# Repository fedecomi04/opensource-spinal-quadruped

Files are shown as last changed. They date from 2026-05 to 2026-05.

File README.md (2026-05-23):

# ASTRA — Quasi-Direct-Drive Spinal Quadruped

**Active Spine Technology for Robotic Agility** — an open-source 9.5 kg quadruped robot with a 3-DoF active spine, built as a B.Sc. thesis at TU München. Designed to be reproducible by hobbyists and labs for around **€1 500**, with full mechanical CAD, embedded firmware, and ROS 2 control stack.

<p align="center">
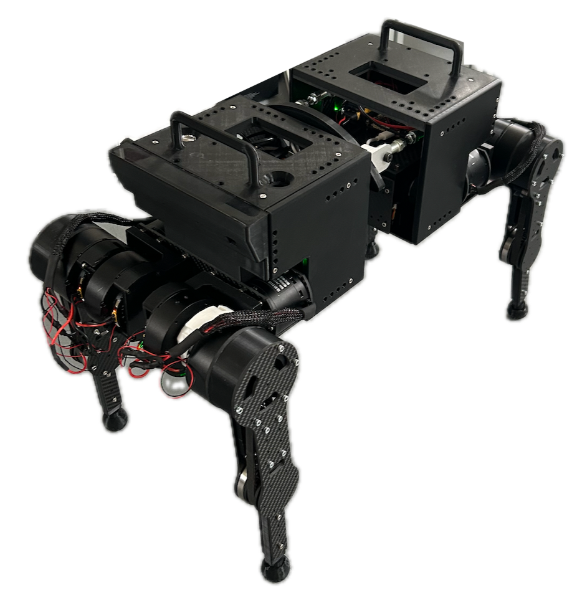
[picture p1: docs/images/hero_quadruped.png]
ASTRA quadruped
  
</p>

---

## Why this project

The 2020s have seen quadrupeds like Unitree's **Go2** (~€2 800) and Boston Dynamics' **Spot** (~€75 000) move from labs into the consumer/industrial market. But almost every commercial platform has a **rigid torso**. Biology disagrees: cheetahs, dogs and horses use their spine to extend stride, store elastic energy and rotate the body in flight.

ASTRA is a **research platform built specifically to study active spines**, with a parallel three-DoF spine that can be locked rigid (to baseline against rigid-torso behaviour) or driven actively. The full stack — CAD, firmware, ROS 2 nodes, MuJoCo sim — is released so anyone with a printer, a soldering iron and a ~€1.5k budget can rebuild it and run new control algorithms.

<p align="center">
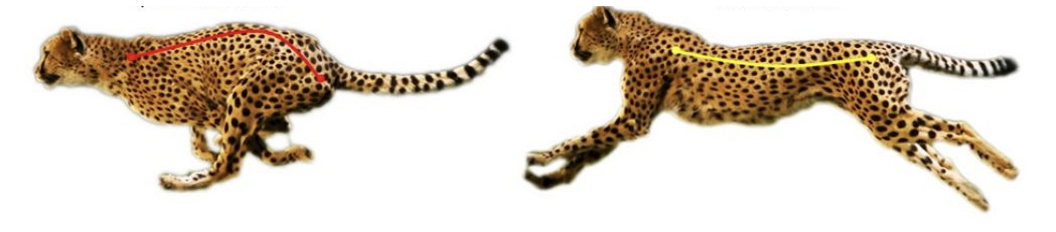
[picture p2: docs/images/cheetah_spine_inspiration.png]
Cheetah spine flexion
  
  <br/>
  <em>Biological inspiration: spine flexion/extension in a running cheetah.</em>
</p>

---

## Key specifications

| | ASTRA | MIT Mini Cheetah | ANYmal | Spot |
|---|---|---|---|---|
| **Mass** | **9.5 kg** | 9.0 kg | 50 kg | 32.7 kg |
| **Dimensions (l × w × h)** | **565 × 287 × 435 mm** | 480 × 270 × 300 | 930 × 530 × 890 | 1100 × 500 × 700 |
| **Max speed** | 4 cm/s¹ | 3.9 m/s | 1.3 m/s | 1.6 m/s |
| **Autonomy** | ~25 min | 30–120 min | 90 min | 90 min |
| **Active-spine DoF** | **3** | 0 | 0 | 0 |
| **Total DoF** | 15 (3 × 4 legs + 3 spine) | 12 | 12 | 12 |
| **Estimated build cost** | **~€1.5 k** | — | — | — |

¹ With the current hard-coded open-loop trot. The mechanical platform is designed for >1 m/s once a proper MPC / learned controller is added.

---

## Demos

### Balance on an inclined plane — real hardware

The spine actively rotates so that either the **front** or the **rear** body stays horizontal on a slope — selected by a single flag in the controller.

**Front body kept horizontal:**

<p align="center">
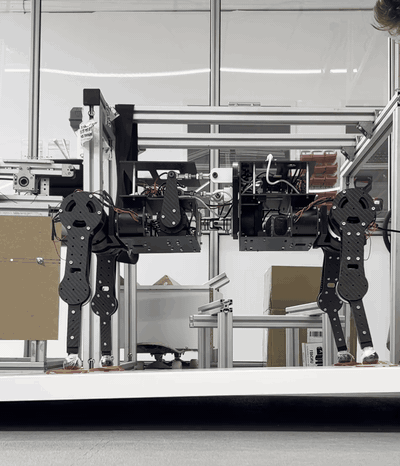
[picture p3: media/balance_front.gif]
  
</p>

**Rear body kept horizontal:**

<p align="center">
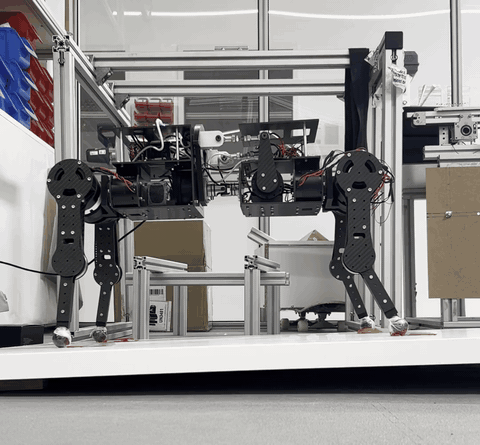
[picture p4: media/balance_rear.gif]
  
</p>

### Trot gait — MuJoCo simulation

The trot controller running in the MuJoCo physics simulation. Every algorithm is validated here before being deployed to the physical robot.

<p align="center">
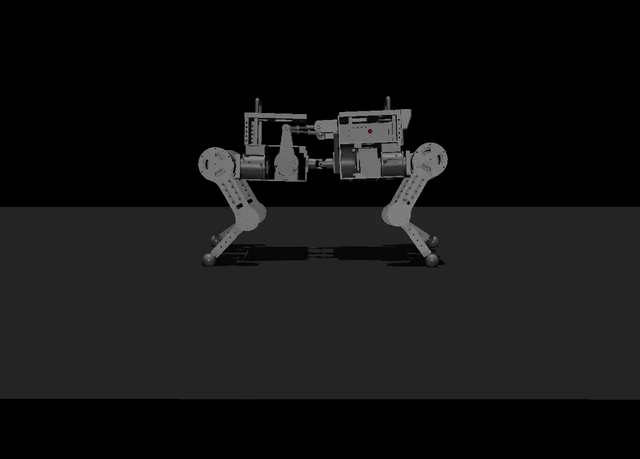
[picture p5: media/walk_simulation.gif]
  
</p>

> Full-resolution MP4 versions of all three clips are also in [`media/`](media/) (and as downloadable assets on the [`demos-v1` release](https://github.com/fedecomi04/opensource-spinal-quadruped/releases/tag/demos-v1)).

### Trot gait — real hardware (still)

<p align="center">
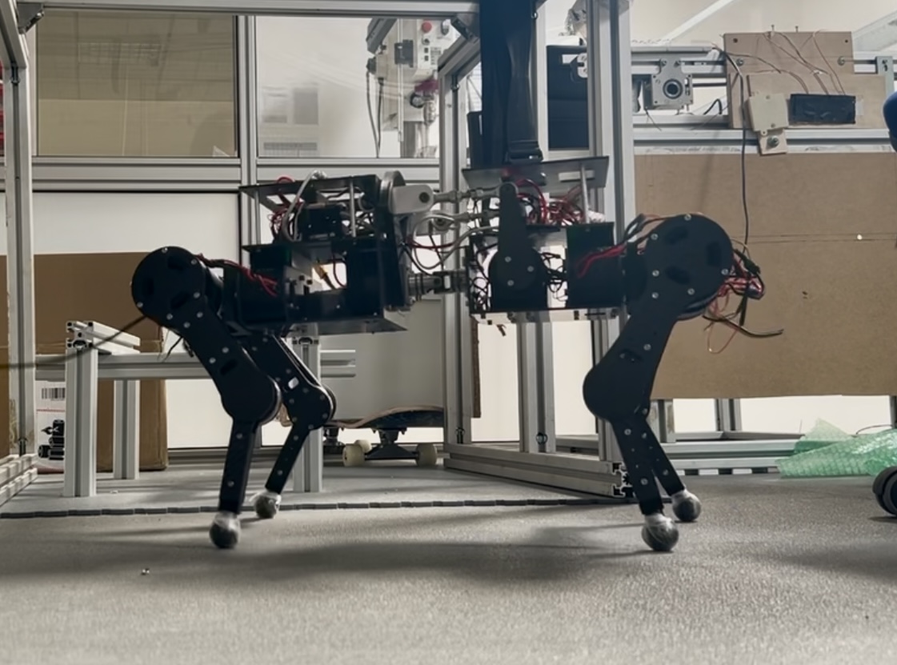
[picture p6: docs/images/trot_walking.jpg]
  
</p>

Hard-coded closed-loop quintic foot trajectory, diagonal pairs in phase, ~4 cm/s on the physical robot.

---

## Hardware

### Actuators — quasi-direct drive

| Joint | Motor | Qty | Reduction |
|---|---|---|---|
| Hip & waist (per leg) | Damiao **DM6006** | 8 | direct (1:1) |
| Knee (per leg) | Damiao **DM6006** | 1 + belt | **1.5:1 belt** → QDD |
| Spine (3 DoF) | Damiao **DM4010** | 6 | direct |

15 motors total. All Damiao motors integrate the BLDC driver on-board and expose a **CAN-FD** interface accepting MIT-mode torque control (θ, ω, K<sub>p</sub>, K<sub>d</sub>, τ<sub>ff</sub>). No external ESCs.

### Electronics architecture

<p align="center">
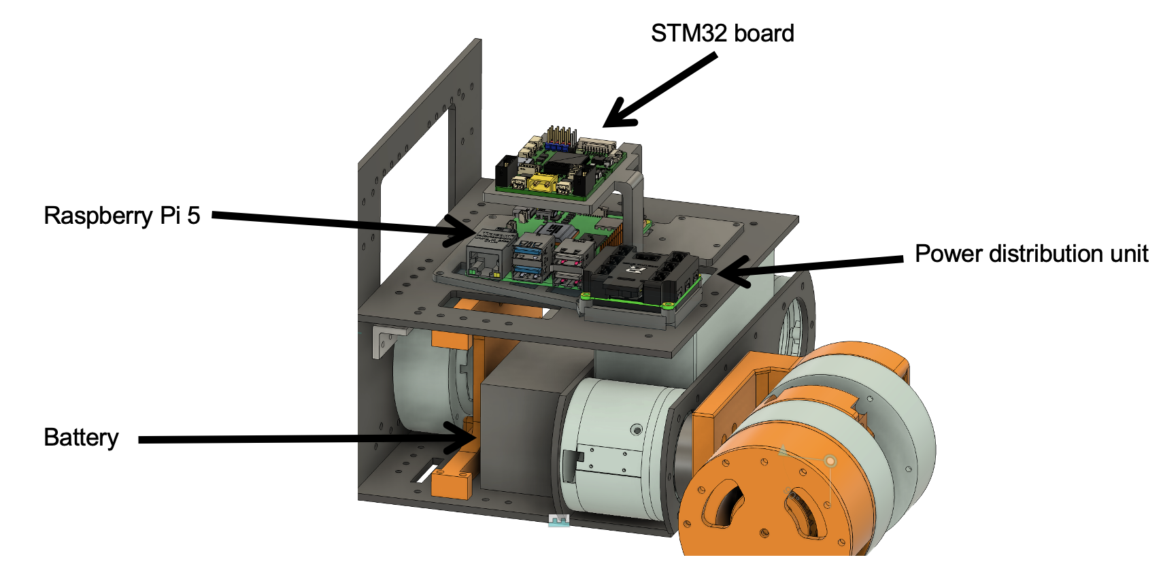
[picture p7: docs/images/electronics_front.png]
Front electronics
  
</p>

```
                        ┌─────────────────────────────┐
                        │     Raspberry Pi 5 (brain)  │
                        │     ROS 2 Jazzy, Ubuntu     │
                        └──────┬───────────────┬──────┘
                          USB  │               │  USB
                  ┌────────────▼───┐     ┌─────▼──────────┐
                  │  Front STM32H7 │     │  Rear STM32H7  │
                  │  (CAN bridge)  │     │  (CAN bridge)  │
                  └───┬────────┬───┘     └──┬───┬────┬────┘
                FDCAN1│  FDCAN2│        FDCAN1│ 2 │  3
                  ┌───▼─┐   ┌──▼─┐         ┌──▼┐ │  │
                  │FR M │   │FL M│         │RR M│ │  └─ spine
                  └─────┘   └────┘         └────┘ └─ RL M
```

- **Pi 5** acts as the brain — runs all ROS 2 nodes (non-real-time).
- **2 × STM32H723VG** boards handle the real-time CAN-FD bus (one per body half). Pi → STM32 over USB, STM32 → motors over CAN-FD at 1 Mbit/s arbitration + 5 Mbit/s data.
- **RoboMaster PDU** distributes 24 V from a 6S LiPo battery to the motors; the Pi runs off a separate power bank so a kill-switch can cut motor power without shutting down the controller.

This split lets you swap the Pi for any other host with a USB port — the motor stack stays intact.

### Mechanical design

<p align="center">
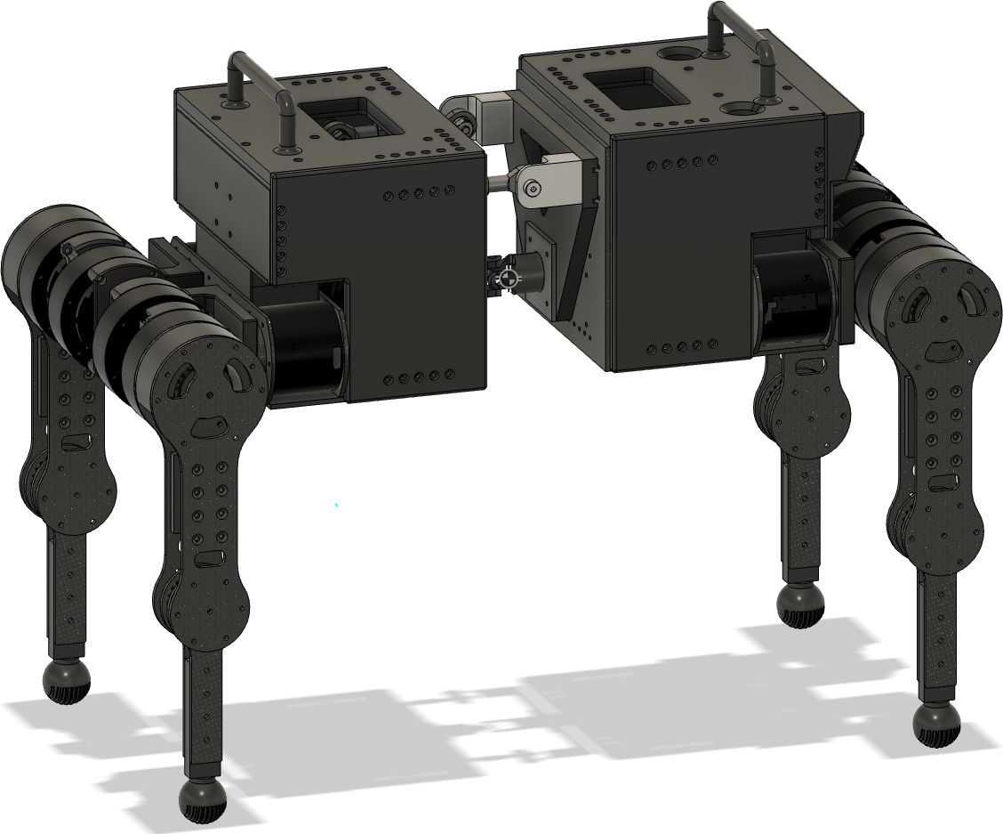
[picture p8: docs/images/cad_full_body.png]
  
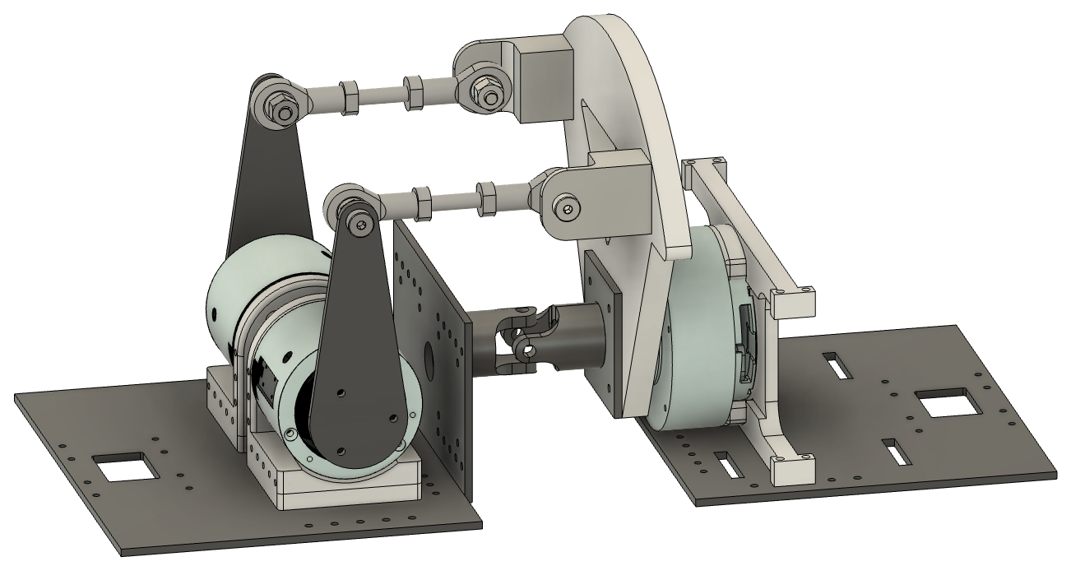
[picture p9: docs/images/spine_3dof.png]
  
  <br/>
  <em>Left: full body. Right: parallel 3-DoF spine mechanism (pitch, roll, yaw via 2 actuators + universal joint).</em>
</p>

- **CFRP** (carbon-fibre) frame and leg links — light, stiff, cheap to laser-cut.
- **Tough PLA** for the brackets and covers — printable on any consumer FDM printer.
- **Steel** link rods + universal joint for the spine.
- **1.5:1 toothed belt** at the knee for the QDD reduction.

### Mass breakdown

<p align="center">
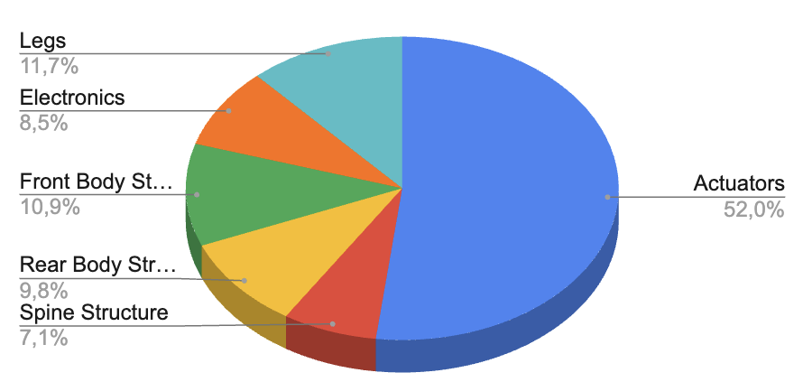
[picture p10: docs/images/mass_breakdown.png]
Mass distribution
  
</p>

| Subsystem | Mass [kg] | % of total |
|---|---:|---:|
| Actuators (15 motors) | 4.95 | 52 % |
| Front body structure | 1.04 | 11 % |
| Rear body structure | 0.94 | 10 % |
| Electronics (Pi, STM32, PDU, battery, wiring) | 0.86 | 9 % |
| Spine assembly | 0.67 | 7 % |
| Legs (4 ×) | 1.12 | 12 % |
| **Total** | **9.5** | **100 %** |

---

## Software

### ROS 2 nodes (`ros2_ws/src/`)

| Node | Role |
|---|---|
| `leg_command/` | Low-level motor command publisher. Accepts `"leg,joint,command"` strings and produces the 14-byte USB → CAN-FD frames for any single Damiao motor. Lets you fire one motor at a time from `ros2 topic pub` — invaluable for hardware bring-up. |
| `mujoco_interface/` | Bridges ROS 2 ↔ MuJoCo. Subscribes to `actuator_goal_rad` (15-vector of joint targets) and drives the simulated robot. Publishes a simulated `imu_data` topic. Supports both position and torque (PD) control modes. |
| `hardware_check/` | Boot-time calibration helper. On startup zeroes every motor in MIT mode, then walks through the 5 legs (FR, FL, RR, RL, S) at 5-second intervals so you can hand-position each one at its mechanical zero. |
| `trot/` | Hard-coded trot gait. Computes per-leg foot trajectories from a quintic smoothing function with configurable stride period, duty factor, swing height and phase offsets. Runs IK on each foot target to produce joint goals at 100 Hz, then publishes MIT commands at 33 Hz with a smooth gain ramp. |
| `spine_roll_inclined_plane/` | Inclined-plane balance controller. Reads IMU pitch, then drives the spine and rear legs so that either the **front** or **rear** body stays horizontal — selected by a single flag. |

<p align="center">
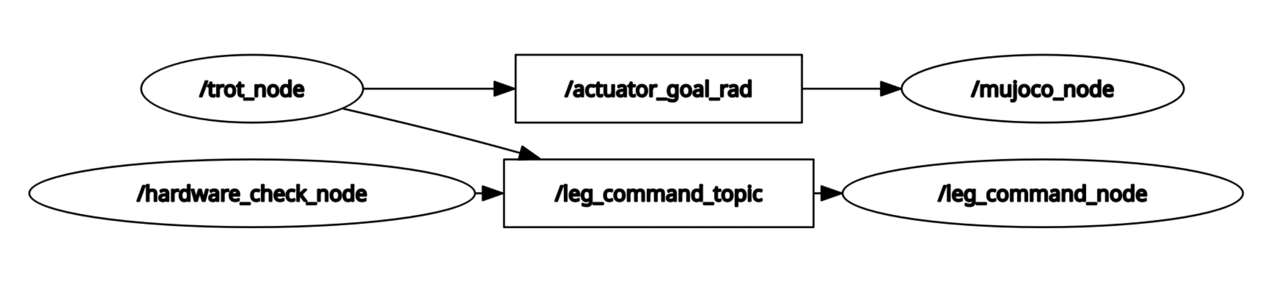
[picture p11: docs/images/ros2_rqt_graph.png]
ROS 2 rqt graph
  
  <br/>
  <em>Live rqt_graph of the running system.</em>
</p>

### STM32 firmware (`firmware/`)

Two STM32CubeIDE projects (`front_stm32/`, `rear_stm32/`) for the **STM32H723VG**:
- 2–3 FDCAN peripherals per board, each connected to one motor bus.
- USB CDC for Pi communication. Every 14-byte USB packet is unpacked into a CAN frame and forwarded.
- Receive interrupt callback re-packages CAN replies (e.g. motor position/velocity feedback) into USB packets for the Pi.

### Simulation (MuJoCo)

The **full MuJoCo simulation is shipped in the repo** at [`ros2_ws/src/mujoco_interface/model/`](ros2_ws/src/mujoco_interface/model/):

- `model.xml` — main MuJoCo model of the whole robot (bodies, joints, actuators, sensors, IMU).
- `quadruped_UJ_activated.xml` — variant with the universal-joint spine activated, used for spine-control experiments.
- `meshes/` — 24 STL meshes for every body half, leg link (FR/FL/RR/RL × hip/femur/tibia) and spine part, exported directly from the Fusion 360 CAD so the visual + collision geometry matches the real hardware.

The `mujoco_interface` node runs the physics in-process, exposes the same ROS 2 topics as the real hardware (`actuator_goal_rad` for commands, `imu_data` for the simulated IMU), and lets you bring up any new controller against the simulator first.

<p align="center">
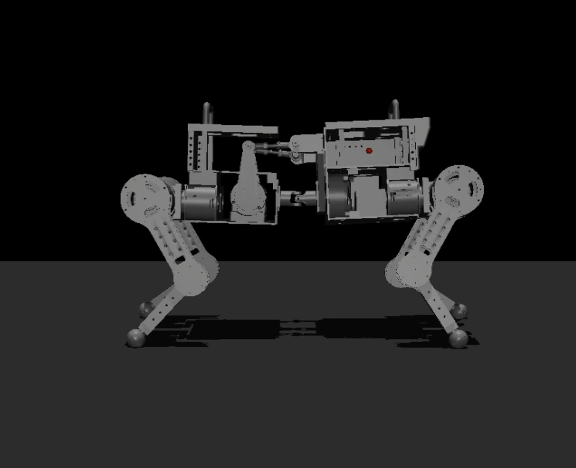
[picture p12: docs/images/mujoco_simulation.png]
MuJoCo simulation
  
</p>

---

## Joint naming convention

<p align="center">
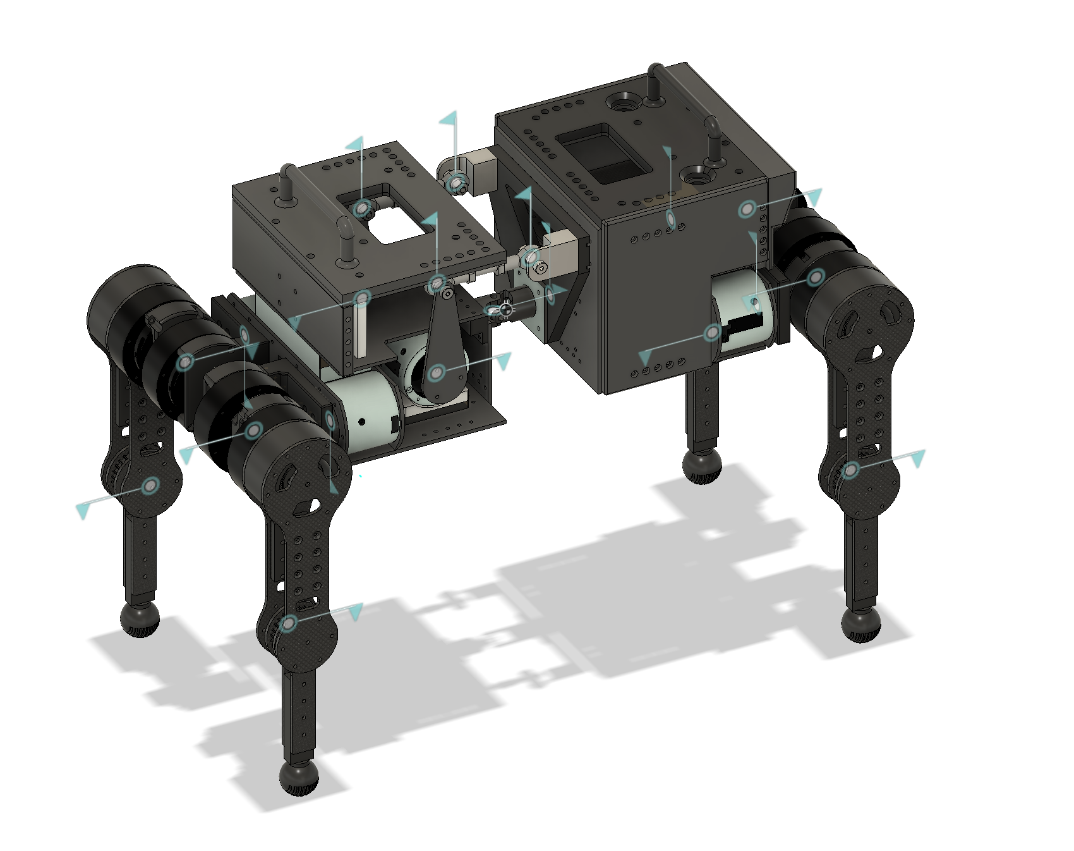
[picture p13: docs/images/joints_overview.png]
  
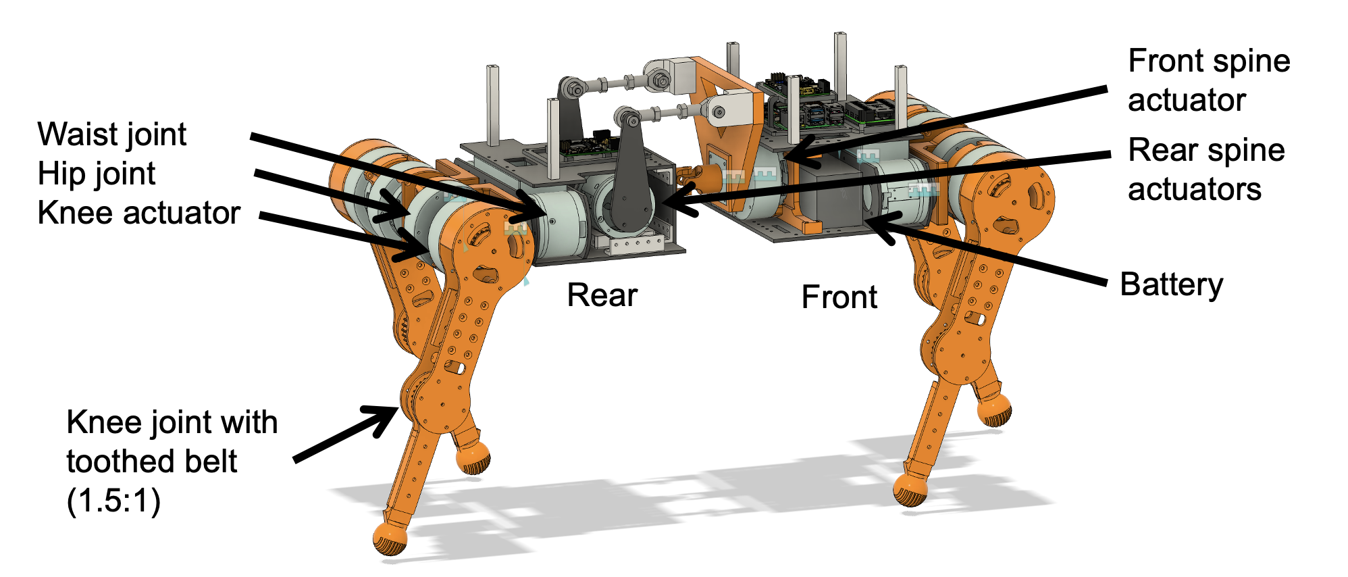
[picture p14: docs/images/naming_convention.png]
  
</p>

Legs are indexed **1 = FR, 2 = FL, 3 = RR, 4 = RL**, joints **1 = waist, 2 = hip, 3 = knee**. Spine joints are **1 = front actuator, 2 = rear-left actuator, 3 = rear-right actuator** (treated as "leg 5" in the codebase for uniformity).

---

## CAD

The full mechanical assembly is shared on Fusion 360:

> **Live Fusion 360 model:** https://a360.co/3KbGvEp

A neutral [`cad/ASTRA_quadruped.step`](cad/ASTRA_quadruped.step) (~20 MB) is included for any CAD tool. STL exports for the 3D-printed parts can be generated directly from the STEP/Fusion model.

---

## How to build one

Rough order of operations to reproduce ASTRA:

1. **Order the motors** — 9 × Damiao DM6006 + 6 × Damiao DM4010 (the bulk of the budget).
2. **Cut the CFRP frame and leg parts** from the STEP file. A local laser-cutting service is fine.
3. **3D-print the Tough PLA brackets** (see `99_3DPrint` in the thesis appendix for print settings — Bambu Lab P1S / Prusa MK4 both tested).
4. **Wire the electronics**: 1 × Raspberry Pi 5, 2 × STM32H723VG dev boards, 2 × RoboMaster M3508 PDU, 1 × 6S LiPo (~5000 mAh), 1 × IMU.
5. **Flash the firmware**: open `firmware/front_stm32/` and `firmware/rear_stm32/` in STM32CubeIDE and flash each board (set the appropriate STM32 in the IDE — STM32H723VG).
6. **Set up the Pi**: install ROS 2 Jazzy on Ubuntu 24.04, `colcon build` the workspace in `ros2_ws/`.
7. **Bring-up**: launch `hardware_check` to zero every joint, then `mujoco_interface` to verify the model, then `trot` to walk.

Detailed step-by-step is in **Chapter 5** of [the thesis](docs/thesis_ASTRA_quadruped.pdf).

---

## Repo layout

```
spinal-quadruped/
├── README.md
├── LICENSE
├── .gitignore
├── docs/
│   ├── thesis_ASTRA_quadruped.pdf   # Full B.Sc. thesis (62 pages + appendix)
│   └── images/                      # Figures used in this README
├── cad/
│   └── ASTRA_quadruped.step         # Neutral CAD export (20 MB)
├── firmware/
│   ├── front_stm32/                 # STM32CubeIDE project, front body
│   └── rear_stm32/                  # STM32CubeIDE project, rear body
├── ros2_ws/
│   └── src/
│       ├── leg_command/             # Low-level USB→CAN motor publisher
│       ├── mujoco_interface/        # ROS 2 ↔ MuJoCo bridge
│       ├── hardware_check/          # Boot-time joint zero / hold helper
│       ├── trot/                    # Hard-coded trot gait + IK
│       └── spine_roll_inclined_plane/  # Inclined-plane balance controller
└── media/                           # Real-hardware demo videos
```

---

## Author & acknowledgements

**Federico Cominelli** — B.Sc. Mechanical Engineering, TU München, 2025.

Reach out via [GitHub](https://github.com/fedecomi04).

Supervised by **Mr. Lingchong Gao** (Chair of Materials Handling, Material Flow, Logistics — fml) and **Mr. Liangyu Dong** (Chair of Robotics, AI and Real-time Systems), under **Prof. Dr.-Ing. Johannes Fottner**, TU München School of Engineering and Design.

Submitted September 2025.

---

## License

Released under the **MIT License** — see [LICENSE](LICENSE). The Damiao motor headers and ST CubeMX-generated HAL drivers retain their original licenses. The MuJoCo headers bundled in `ros2_ws/src/mujoco_interface/include/mujoco/` are © Google / DeepMind under the Apache 2.0 license.

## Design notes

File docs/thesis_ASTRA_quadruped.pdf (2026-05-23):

# Entwicklung eines quadrupeden Roboters mit aktiver Wirbelsäule und quasi-direktem Antrieb

# Development of a Quasi-Direct Drive Spinal Quadruped Robot

### Wissenschaftliche Arbeit zum Erlangen des akademischen Grades

B. Sc.

### an der School of Engineering and Design der Technischen Universität München

Themenstellender: | Prof. Dr.-Ing. Johannes Fottner
| Lehrstuhl für Fördertechnik Materialfluss Logistik
Betreuer/Betreuerin: | Mr. Lingchong Gao and Mr. Liangyu Dong
Eingereicht von: | Federico Cominelli (, B. Sc.)
| Boltzmannstrasse 15
| 85748 Garching bei München
| +33 6 43 91 76 13
Eingereicht am: | 01.09.2025 in Garching
Inventarnr. fml: | 2025/78

## Vorwort

Die vorliegende Arbeit entstand unter der wissenschaftlichen und inhaltlichen Anleitung von Mr. Lingchong Gao, wissenschaftlicher Mitarbeiter am Lehrstuhl für Fördertechnik, Materialfluss und Logistik (fml) der Technischen Universität München, sowie von Mr. Liangyu Dong am Lehrstuhl für Robotik, Künstliche Intelligenz und Echtzeitsysteme der Technischen Universität München.

### Vereinbarung zum Nutzungsrecht

Hiermit gestatte ich dem Lehrstuhl für Fördertechnik Materialfluss Logistik diese Studienar-beit bzw. Teile davon nach eigenem Ermessen an Dritte weiterzugeben, zu veröffentlichen oder anderweitig zu nutzen. Mein persönliches Urheberrecht ist über diese Regelung hinaus nicht beeinträchtigt. Eventuelle Geheimhaltungsvereinbarungen über den Inhalt der Arbeit zwischen mir bzw. dem Lehrstuhl für Fördertechnik Materialfluss Logistik und Dritten bleiben von dieser Vereinbarung unberührt.

Garching, 01.09.2025

## Abstract

This thesis presents the development of a quasi-direct drive quadruped robot with a three-degree-of-freedom spine, designed to serve as a research platform for future studies in locomotion and control.The quadruped was engineered to be mechanically robust enough to perform stable walking and balancing while integrating additional flexibility through its articulated spine. The work involved mechanical design and manufacturing, the integration of high-performance actuators and sensors, and the development of embedded control software using one Raspberry Pi 5 and the ROS 2 framework. A MuJoCo-based simulation environment was created to validate control strategies before hardware testing. The robot successfully demonstrated two key capabilities: trotting at a constant speed of 4 cm/s using a hard-coded closed-loop trajectory, and balancing on an inclined plane. The software’s modular design allows for easy implementation of advanced gait generation, real-time optimization, and spine-assisted locomotion strategies.

## Contents

1 | Introduction | 1
1.1 Introduction | 1
1.2 Related Work | 1
1.3 Goal of this Thesis | 3
1.4 Structure of the Thesis | 4
2 | Hardware Design | 6
2.1 General Overview | 6
2.2 Actuator Choice | 8
| 2.2.1 Actuator Choice | 8
2.3 Electronics Hardware | 9
| 2.3.1 Electronics choice | 9
| 2.3.2 Electronics Architecture | 11
| 2.3.3 Communication frequency | 12
| 2.3.4 USB communication protocol | 12
| 2.3.5 FDCAN communication protocol | 13
| 2.3.6 Damiao motor commands | 15
2.4 Mechanical Design | 16
| 2.4.1 Frame and supports | 16
| 2.4.2 Leg Design | 17
| 2.4.3 Spine Design | 21
3 | Control | 26
3.1 Approach | 26
3.2 Inverse Kinematics and Forward Kinematics of the leg | 26
| 3.2.1 Forward Kinematics | 28
| 3.2.2 Inverse Kinematics | 29
3.3 Inverse Kinematics and Forward Kinematics of the spine | 32
| 3.3.1 Inverse Kinematics | 32
| 3.3.2 Forward Kinematics | 35
| | II

Contents

3.4 Gait: trot equations | 36
3.5 Balance on an inclined surface | 37
| 3.5.1 Rear body balance | 38
| 3.5.2 Front body balance | 38
| 3.5.3 Legs | 39
4 | Software Design | 41
4.1 Introduction | 41
4.2 Joints Notation | 41
4.3 ROS 2 architecture | 42
| 4.3.1 leg_command_node.cpp | 42
| 4.3.2 mujoco_node.cpp | 44
| 4.3.3 hardware_check.cpp | 45
| 4.3.4 trot_node.cpp | 47
| 4.3.5 spine_pitch_inclined_plane_node.cpp | 49
4.4 MuJoCo Simulation | 52
| 4.4.1 Control | 53
| 4.4.2 XML Models | 53
| 4.4.3 Sensor IDs | 53
| 4.4.4 Inclined Plane | 54
5 | Testing and Results | 55
5.1 Testing Procedure and Recommendations | 55
| 5.1.1 MIT Position Limits | 55
| 5.1.2 Communication Setup | 55
| 5.1.3 Useful Commands | 55
| 5.1.4 Final Recommendations | 56
5.2 Results | 56
| 5.2.1 Hardware Analysis | 56
| 5.2.2 Test cases choice | 59
6 | Conclusion | 62
| | III

Contents

Literaturverzeichnis | 63
7 | List of Figures | 66
8 | List of Tables | 68
A Anhang | A-1
A.1 Code Listings | A-1

IV

## 1 Introduction

### 1.1 Introduction

Quadruped robots have gained significant attention in recent years due to their versatility, mobility, and potential applications in environments that are inaccessible or hazardous to humans. Their ability to traverse uneven terrain and maintain stability under perturbations makes them valuable platforms for research in locomotion control, and robotic autonomy.

This thesis focuses on the development of a quasi-direct drive quadruped robot with a three-degree-of-freedom spine, designed as a research platform for future work on locomotion and control strategies.

### 1.2 Related Work

The development of quadruped robots has progressed rapidly over the past two decades. Early prototypes in the late 1990s and early 2000s, such as Raiberts quadrupeds at the MIT Leg Lab, were primarily research platforms used to explore basic locomotion and gait control strategies [Rai-1986], [Lee-1996]. At that time, most quadrupeds relied on relatively simple gait generators and rigid torsos, but they already demonstrated the potential of legged systems to traverse uneven terrain where wheeled robots fail. A major milestone was reached with Boston Dynamics BigDog (2005 - 2008), which introduced hydraulically actuated legs and showed unprecedented robustness on rough terrain, pushing quadrupeds from laboratory prototypes toward field-capable machines [Rai-2008]. During the 2010s, progress accelerated with the introduction of more advanced actuators and control frameworks, leading to robots such as HyQ (2011) [Sem-2011] and ANYmal (2016) [Hut-2016]. Since then, quadrupeds have become increasingly refined, with better actuators, more powerful control algorithms, and improved mechanical designs, enabling robust dynamic locomotion and even commercial applications.

Among the most famous quadrupeds today are ANYmal from ETH Zurich, the MIT Cheetah family, and HyQ from the Italian Institute of Technology. ANYmal is torque-controlled and uses serieselastic actuation combined with wholebody control, which allows it to perform robust and dynamic movements [Hut-2016], [Bel-2017]. HyQ is hydraulically actuated and showed that high force and robustness could be achieved in quadruped robots [Sem-2011]. The MIT Cheetah series pushed the field further by introducing proprioceptive electrical actuators and advanced model predictive control (MPC), allowing dynamic running and jumping behaviors [Ble-2018], [DiC-2018]. Smaller and more accessible platforms were later introduced, such as the MIT Mini Cheetah [Kat-2019] and Stanford Doggo [Kau-2019], which used quasidirect drive actuators to lower cost and complexity while still enabling dynamic gaits. Reinforcement learning has also started to play an important role, for example with ANYmal, where learning-based controllers demonstrated agile locomotion directly on

1 Introduction

hardware [Hwa-2019]. Finally, Boston Dynamics Spot is an example of how quadrupeds have moved from research into commercial use, with reliable autonomy for inspection and mapping tasks.

Table 1-1 summarizes the specifications of some of these quadrupeds and compares them with the ASTRA prototype developed in this thesis.

Table 1-1: | Specifications of selected quadrupeds compared to the developed prototype.
Quadruped | Mass [kg] Dim (l,w,h) [mm] Max Speed [m/s] Autonomy [min]
MIT Mini Cheetah | 9.0 | 480 ⇥ 270 ⇥ 300 | 3.9 | 30–120
ASTRA | 9.5 | 565 ⇥ 287 ⇥ 435 | 0.04 | 25
ANYmal | 50 | 930 ⇥ 530 ⇥ 890 | 1.3 | 90
Spot | 32.7 | 1100 ⇥ 500 ⇥ 700 | 1.6 | 90
Figure 1-1: | From left to right: MIT Mini Cheetah (MIT), ANYmal (ETH Zurich), Spot (Boston Dynamics).

As rigid-torso quadrupeds have reached a very advanced stage of development, with some even commercialized, research interest has started to shift towards robots with active spines. In nature, animals such as cheetahs use their flexible spine to increase stride length, running speed, and efficiency. This biological inspiration motivates the design of quadrupeds with actuated spines.

Figure 1-2: Spine flexion and extension in a running cheetah.

1 Introduction

Initial studies explored very simple spine designs. For example, early prototypes with only one degree of freedom (DoF) in the sagittal plane showed that an actuated spine can support bounding locomotion [Lee-1996]. Later experiments confirmed that bending the spine could increase speed and improve stability, although sometimes at the cost of efficiency [Kho-2013]. Other works, such as the Inu and Canid robots from Koditschek Lab, introduced a parallel elastic and powered spine, demonstrating experimentally that spinal actuation helps with self-manipulation and with overcoming obstacles [Dup-2017], [Pus-2013]. At the same time, several groups studied active spines in simulation, using trajectory optimization or simplified models to show potential benefits of twisting, extending, or prismatic spines [Ye-2021], [Cap-2023].

More recently, researchers have built quadrupeds with spines of multiple DoFs. The Stoch 2 robot included a two-DoF spine and applied reinforcement learning to learn bounding behaviors that actively used the spine [Bha-2019]. Yat-sen Lion incorporated a three-DoF spine, where the control problem was addressed by extending model predictive control to handle the changing center of mass and inertia of the body [Li-2023]. STRAY represents one of the most advanced prototypes: it uses a four-DoF symmetric five-bar spine mechanism and a hybrid control approach combining trajectory references with reinforcement learning [Wan-2024]. These studies show that while spine actuation can sometimes increase energy cost at low speeds, it tends to provide clear advantages for more dynamic tasks, such as high-speed running, long jumps, and wall-assisted leaps [Dup-2017], [Cap-2023], [Wan-2024].

In this context, the present work introduces ASTRA, a lightweight research quadruped designed with a modular spine that can behave either as a rigid torso or as an actuated joint. This allows direct comparison between rigid and active torso designs on the same platform. Furthermore, the electronics and software were built to support both model-based control strategies (such as MPC [DiC-2018], [Li-2023]) and learning-based methods (such as RL [Hwa-2019], [Wan-2024]), providing a flexible testbed for future research on how spines should be controlled in quadrupeds.

### 1.3 Goal of this Thesis

The primary objective of this thesis is to design and build a spinal quadruped robot ensuring that it is robust enough to walk, balance, and serve as a reliable foundation for further research.

To achieve these objectives, the work covers:
- The manufacturing and design of the mechanical structure and electronic components.
- Integration of quasi-direct drive actuators and an IMU.
- Development of control software using a Raspberry PI 5 and ROS 2.
- Simulation-based validation using MuJoCo before hardware testing.
- Experimental verification through trotting and balancing tasks.

1 Introduction

### 1.4 Structure of the Thesis

The thesis is organized in a chronological manner, beginning with the design and assembly phase, followed by the derivation of kinematics and control equations, then the description of the software architecture, and finally the presentation of experimental results:
- Chapter 1 introduction
- Chapter 2 details the mechanical and electronics design.
- Chapter 3 presents the kinematics derivations, and contol strategies for the two test cases (trot and balance).
- Chapter 4 describes the software architecture, ROS 2 nodes, and the MuJoCo simulation setup.
- Chapter 5 outlines the testing procedures, and experimental results.

The quadruped presented is the following:

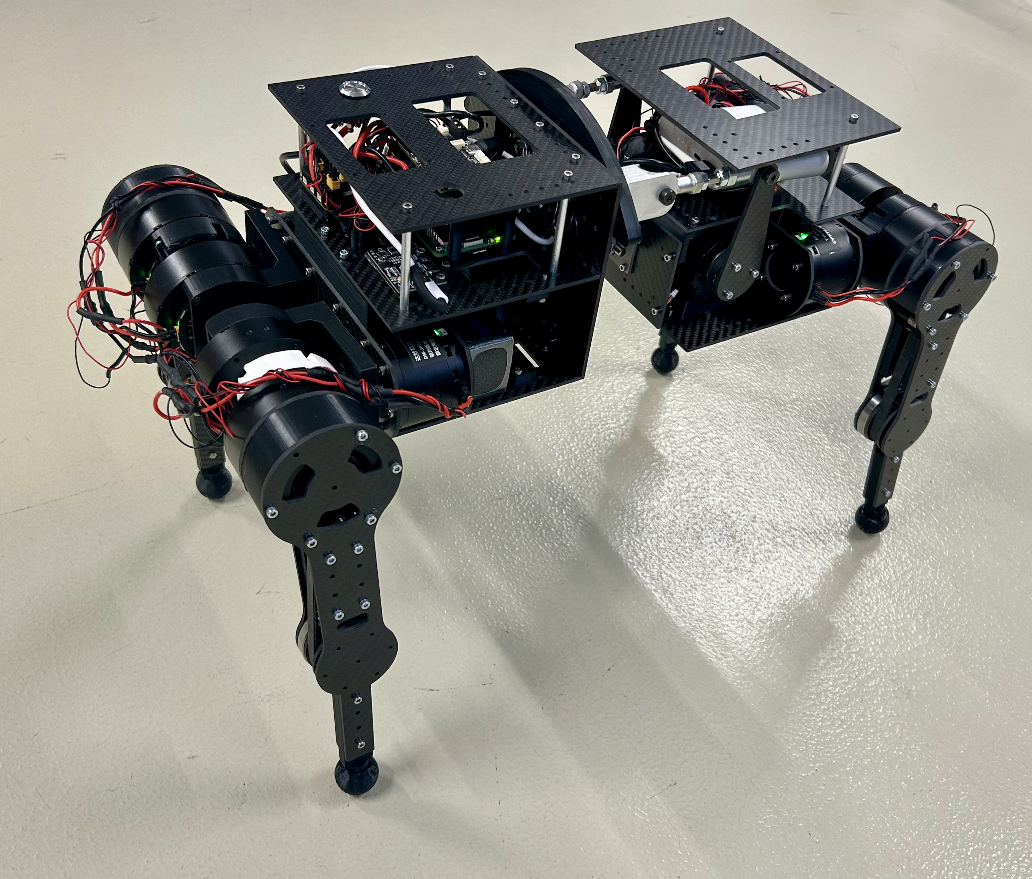
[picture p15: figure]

Figure 1-3: Picture of the quadruped without sideplates

It was named ASTRA, an acronym for Active Spine Technology for Robotic Agility. The name emphasizes the central innovation of the platform: the integration of an actuated spine to enhance locomotion performancewhile also reflecting its intended characteristics of speed,

1 Introduction

agility, and robustness. Beyond the acronym, Astra is derived from the Latin word for stars, evoking ambition and reliability, and historically associated with exploration and endurance; watching stars, you never get lost.

## 2 Hardware Design

### 2.1 General Overview

The quadruped has 15 motors which control 15 degrees of freedom: 3 per leg and 3 for the spine. It weighs 9.5 kg and achieves a maximum walking speed of 4 cm/s in its current hard-coded trot gait. It features an active spine with three degrees of freedom positioned between two rigid bodies, allowing for enhanced maneuverability and dynamic posture control. The actuation system is quasi-direct drive, providing backdrivability and precise torque control. The moments of inertia at the center of mass are the following:

Component | Value
Ixx | 0.343
Iyy | 0.077
Izz | 0.363
Ixy = Iyx | 5.317 ⇥ 105
Ixz = Izx | 9.628 ⇥ 106
Iyz = Izy | 0.001
Table 2-1: | Moments of inertia at the center of mass of the quadruped (kg·m²).
Figure 2-1: | Rendering of the quadruped with CoG

2 Hardware Design

Below is an overview of the connections and the placement of the major components in the quadruped. Figure 2-2 presents the main components of the system, their locations, and the communication network. The architecture can be compared to that of the human body: the Raspberry Pi 5 acts as the brain, the actuators (M in the figure) serve as the muscles, and everything in between functions as the nervous system. The STM32 microcontrollers operate only as bridges, transmitting data between the actuators and the Raspberry Pi. Communication between the Pi and the STM32 boards is established via USB, while the STM32 and the actuators communicate through CAN. The RoboMaster module (PDU in the diagram) serves as a power distribution unit: it is connected directly to the battery and provides the 24 V supply to the system. However, the Raspberry Pi 5 is powered by its own dedicated power bank, which makes it possible to include a shutdown button on the quadruped that cuts power to all actuators without interrupting the Pi.

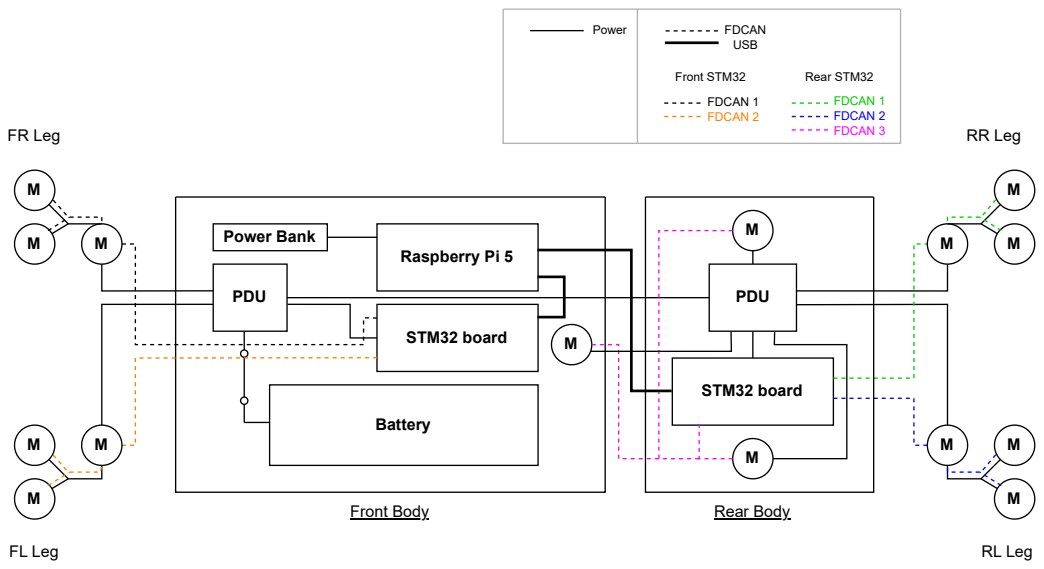
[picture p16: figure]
PDU; Power Bank; Battery; STM32 board; Raspberry Pi 5; Power; FDCAN; USB; FDCAN 1 FDCAN 2; Front STM32; FDCAN 1 FDCAN 2 FDCAN 3; Rear STM32; Front Body; Rear Body; FR Leg; FL Leg; RL Leg; RR Leg

Figure 2-2: General electro-mechanical diagram

The naming convention used is shown in the Figure 2-3 where the actuators are in white:

2 Hardware Design

Figure 2-3: Naming convention

### 2.2 Actuator Choice

### 2.2.1 Actuator Choice

The selection of actuators is a critical design step in robotics, as it directly affects performance, weight, efficiency, and controllability. Several types of actuators are commonly employed in robotic systems:
- Hydraulic actuators: widely used in large-scale robots and industrial machinery for their extremely high power density and force output. They provide smooth motion and high stiffness but require bulky pumps, hoses, and valves, leading to higher system weight, increased maintenance demands, and reduced portability. Their use is therefore limited in small to medium-sized mobile robots.
- Pneumatic actuators: lightweight and inexpensive, capable of producing rapid motions. However, they suffer from low control precision, compressibility of air (which introduces compliance), and the need for external compressors, making them less suitable for quadrupeds where accurate torque and position control are required.
- Series elastic actuators (SEA): these combine a motor with an elastic element to improve shock tolerance and energy storage. SEAs are well suited for safe interaction with humans and for legged locomotion with large impacts, but the addition of elastic elements reduces bandwidth and increases control complexity.
- Electrical direct-drive actuators: provide precise torque control and backdrivability by coupling the motor shaft directly to the load without high-ratio gearing. They offer high transparency and controllability but typically require very large, heavy motors to generate sufficient torque for legged robotics.
- Quasi-direct drive actuators (QDD): a compromise between direct drive and geared solutions. They use low gear ratios (5:115:1), which maintain low reflected inertia and high

2 Hardware Design

backdrivability while still amplifying torque to usable levels. QDD systems are increasingly popular in state-of-the-art quadrupeds because they combine robustness, efficiency, and precise force control while keeping the mass of the actuator moderate.

For this project, electrical actuators were selected, as they are more compact, energy-efficient, and easier to integrate than hydraulic or pneumatic systems in a lightweight quadruped. Within electrical actuators, two main categories are relevant: direct-drive (DD) and quasi-direct drive (QDD).

In a direct-drive configuration, the motor shaft is coupled directly to the joint without gear reduction. This yields maximum transparency, perfect backdrivability, and eliminates backlash or compliance introduced by transmission elements. However, achieving the torque levels required for quadruped knees with DD alone demands large, heavy motors, which increases overall robot mass and reduces efficiency.

Quasi-direct drive actuators address this limitation by introducing a small gear reduction, typically in the range of 5:1 to 15:1. The gear amplifies torque while keeping reflected inertia low enough to preserve backdrivability and force controllability. Compared to high-ratio geared actuators (e.g. 100:1 harmonic drives), QDD maintains nearly the same transparency as DD but allows the use of smaller, lighter, and more efficient motors. This design philosophy has become the standard in modern quadrupeds such as the MIT Mini Cheetah.

In the present quadruped, a mixed approach was adopted. The waist and hip joints are implemented in direct drive, as their torque requirements can be met by the selected motors without gearing. By contrast, the knee joint requires significantly higher torque, for which a 1.5:1 belt transmission was introduced. This classifies the knee as a quasi-direct drive joint, while the waist and hip remain purely direct drive.

The actuators chosen are Damiao brushless DC motors, which integrate both the motor and the driver on a single board. This integration eliminates the need for external driver boards: the motors expose a CAN interface that accepts predefined commands (enable, disable, set zero, request position, MIT-mode torque control, etc.). Consequently, the control architecture only needs to construct and transmit CAN messages, while all low-level motor control tasks such as commutation, current regulation, and protection are handled internally by the integrated driver. This feature drastically simplifies the electronics design and improves system reliability.

### 2.3 Electronics Hardware

### 2.3.1 Electronics choice

Different hardware architectures were considered for the electronic integration of the quadruped. A first option would have been to connect the actuators directly to the main computer (Raspberry Pi 5), without the use of intermediate microcontrollers. This approach

2 Hardware Design

simplifies the hardware and reduces the number of boards, but it places the entire low-level motor communication and protocol handling burden on the host computer. In practice, this means that the host must handle all real-time CAN responsibilities itself, including bit timing, arbitration, retransmissions, acknowledgments, and DLC management. Such a setup would also require additional hardware, typically USB-to-CAN or PCIe-CAN adapters, which increase cost, add failure points, and reduce portability. Furthermore, the absence of an intermediate abstraction layer makes the architecture less modular: if the central computer is replaced, the low-level drivers and CAN interfaces would need to be reimplemented and validated.

A second possibility was to rely on a more powerful onboard computer instead of a Raspberry Pi, still connected directly to the actuators without microcontrollers. This solution would make it possible to run computationally intensive algorithms or vision processing locally, but at the cost of higher weight, larger volume and increased power consumption. Moreover, the same integration problem remains: direct CAN connection to the host still requires external adapters and specialized drivers, which complicates deployment and reduces flexibility.

For this project, a hybrid architecture was therefore selected, combining a Raspberry Pi 5 as the high-level control unit with two STM32 microcontrollers acting as communication bridges. The Raspberry Pi formats and sends the CAN payloads via USB, while the STM32 boards absorb the real-time responsibilities of the FDCAN layer. By offloading arbitration, interrupt-driven transmission scheduling, and low-level protocol compliance to the STM32s, the Raspberry Pi operates as a nonreal-time publisher of high-level commands. This modular approach provides several advantages. First, it allows the Raspberry Pi to be replaced seamlessly by any other computer equipped with a USB port, without requiring modifications to the motor communication layer. This means that future upgrades to a more powerful onboard computer can be implemented immediately by copying the ROS 2 nodes, with no changes to the underlying actuator communication. Second, it simplifies cabling: instead of routing three separate CAN buses along the robot body, only two USB connections are needed, one to the front STM32 and one to the rear, reducing wiring complexity, potential failure points, and overall assembly time.

The choice of CAN as the communication protocol between STM32s and actuators is justified by its robustness and performance. CAN is widely adopted in automotive and industrial applications due to its noise resistance, fault tolerance, and deterministic arbitration, making it well suited for long cable runs in electrically noisy environments. Furthermore, it supports multiple actuators on the same bus without point-to-point wiring, thereby reducing both cost and complexity. Although the inclusion of STM32 boards increases hardware count, their benefits in modularity, future scalability, and independence from specialized USB-to-CAN adapters clearly outweigh the added cost.

2 Hardware Design

In summary, the selected architecture strikes a balance between performance, modularity, and maintainability. By combining a Raspberry Pi with STM32-based CAN bridges, the system remains flexible, portable, and robust, while also ensuring straightforward integration
of future high-performance onboard computers for advanced control algorithms.
Criterion | Direct Computer-to-CAN | Raspberry Pi + STM32 Bridge (selected)
Hardware complexity | Fewest boards, but requires USB-to-CAN or PCIe-CAN adapters | Moderate: one Pi + two STM32 boards, no external adapters needed
Real-time CAN han-dling | Host must manage bit timing, ar-bitration, ACK, retransmission | Offloaded to STM32, host runs nonreal-time ROS 2 only
Modularity / portability | Low: changing host requires new drivers and reconfiguration | High: any USB-capable computer can replace the Pi instantly
Computational capa-bility | Limited by Pi or by chosen host | Flexible: Pi today, easily swap-pable for a high-performance computer tomorrow
Weight / volume | Low | Low to moderate
Cost | High (due to CAN adapters) | Moderate (STM32 cost < adapters, Pi inexpensive)
Robustness in embed-ded use | Sensitive to adapter drivers | Robust, distributed, widely tested MCUs in robotics
Table 2-2: | Comparison of electronic architectures for quadruped integration.

### 2.3.2 Electronics Architecture

The Raspberry Pi acts as the brain of the quadruped, while the STM32 boards serve only as bridges between the 15 actuators and the Pi. The Pi generates and sends a USB message to the STM32, which then forwards the relevant part of the message to the specified FDCAN bus. For simplicity, the frame formats of both USB and FDCAN are constructed on the Pi; the STM32 receives the instruction indicating to which leg and which motor the CAN message should be forwarded. In the following two subsections, the format of each protocol is explained in detail. Figure 2-4 presents a detailed overview of the communication architecture, showing the USB ports, the FDCAN buses, and the actuator IDs.

2 Hardware Design

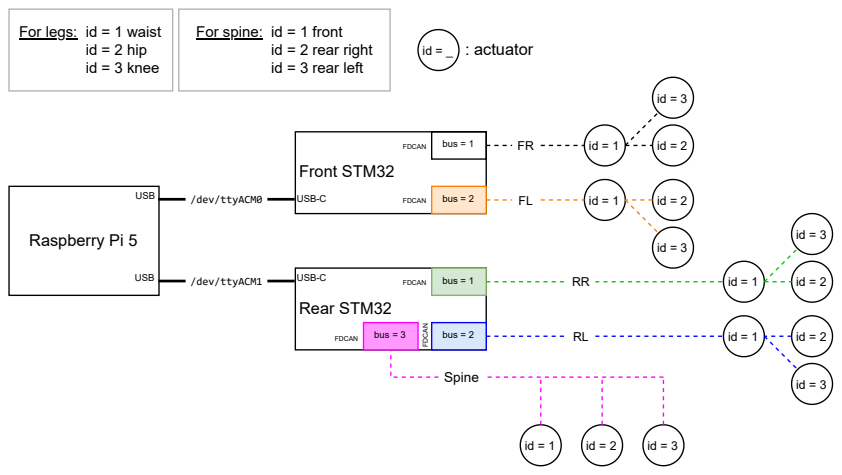
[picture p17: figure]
Raspberry Pi 5; Front STM32; Rear STM32; USB; USB-C; bus = 1; bus = 2; bus = 3; /dev/ttyACM0; /dev/ttyACM1; For legs: id = 1 waist id = 2 hip id = 3 knee; Spine; For spine: id = 1 front id = 2 rear right id = 3 rear left; FDCAN; FDCAN FDCAN; id = _ : actuator

Figure 2-4: Overview of communications with usb ports, can buses and can ids

### 2.3.3 Communication frequency

The STM32H723VGT6 microcontroller is mounted on a custom board provided by Damiao Technology along with the motors. I used the three available CAN-FD ports and the USB-C interface for communication. Before defining the structure of the communication protocols, I first determined the maximum frequency at which messages could be reliably transmitted through the system.

Device | Interface Max Frequency / Baudrate Source
Raspberry Pi 5 USB 3.0 | 5 Gbps | [Ras-2023]
STM32H723 | FDCAN | 8 Mbps (CAN FD) | [ST-2023a]
USB (HS) 480 Mbps | [ST-2023a] Section 3.43
DM Board | CAN FD | 5 Mbps | DM Board PDF, p.2
DM Motors | CAN | 1 Mbps | Motor PDF, CAN@1Mbps
Table 2-3: | Maximum communication frequencies of all devices in the system

Therefore, the maximum frequency is f =1 MBps = 125 Byte/ms

### 2.3.4 USB communication protocol

The USB communication is used between the Raspberry Pi 5 and the two STM32 boards. Each message is 14 bytes long and contains all the information required to control the actuators. The structure of the message is the following:

# 0xAA | {z } Start

# 0x09 | {z } Length

CAN
|{z}
| Bus

ID_H
| | | {z } ID high

ID_L
| | | {z } ID low
D0 D1 D2 D3 D4 D5 D6 D7 | {z } 8-byte CAN data payload

CHK
|{z}
| | | Checksum

2 Hardware Design

Byte Index Field | Meaning
0 | 0xAA | Start byte
1 | 0x09 | Payload length (always 9)
2 | CAN bus | 1 = FDCAN1, 2 = FDCAN2, 3 = FDCAN3
3–4 | CAN ID | 11-bit motor ID (big-endian)
5–12 | Data[0–7] 8-byte CAN payload
13 | Checksum Sum of bytes 212 modulo 256
Table 2-4: | Structure of the USB-to-CAN message format

### 2.3.5 FDCAN communication protocol

The standard CAN FD data frame is the following:

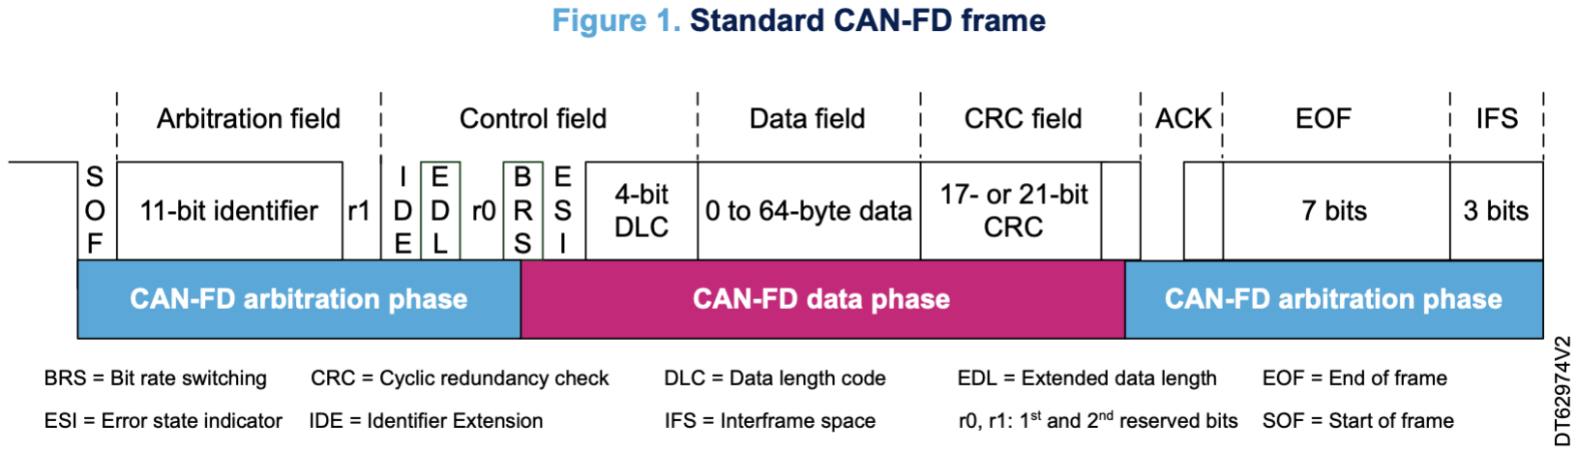
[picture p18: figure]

Figure 2-5: Standard CAN-FD frame (when not specified bit = 1) from [ST-2021]

The three fields that I can modify according to my necessities are: the 11-bit identifier, the 4-bit DLC and the data field.
- 11-bit identifier: it is the can-ID (Figure 2-6)
- 4-bit DLC: size of the data is 8 byte (imposed by DAMIAO Motors)
- Data field: 8 bytes which depend on the command, see next subsection (imposed by DAMIAO Motors)

Once the CAN-FD frame is defined, I had to configure the parameters of the FDCAN accordingly:

2 Hardware Design

Figure 2-6: | FDCAN setup: TX/RX on
STM32 | Figure 2-7: | FDCAN setup: Bit Timing

I recommend using this bit timing calculator for FDCAN (https://kvaser.com/support/calculators/can-fd-bit-timing-calculator/) to calculate these parameters. (a more detailed explanation can be found in this tutorial) (https://www.youtube.com/watch?v=kXyzaaSk6Qs&ab_channel=ControllersTech) They were calculated with the following characteristics:
- frequency = 48 000 kHz
- tolerance = 4 587 Ppm
- node delay = 250 Ns

The Message Ram Offset is calculated this way:

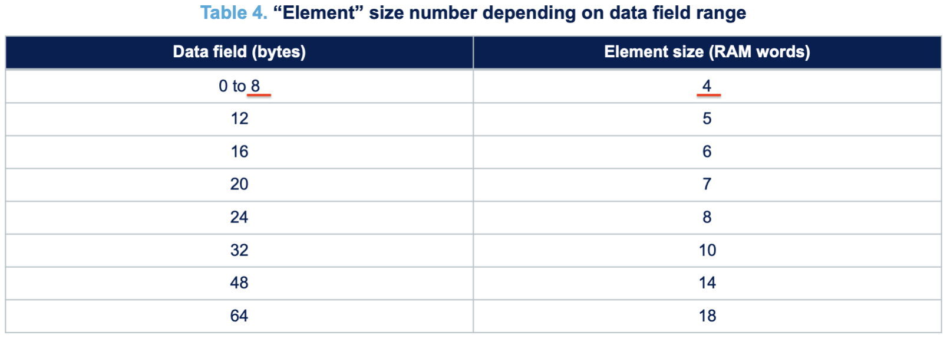
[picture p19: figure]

Figure 2-8: Data field in equivalent RAM words, [ST-2021]

2 Hardware Design

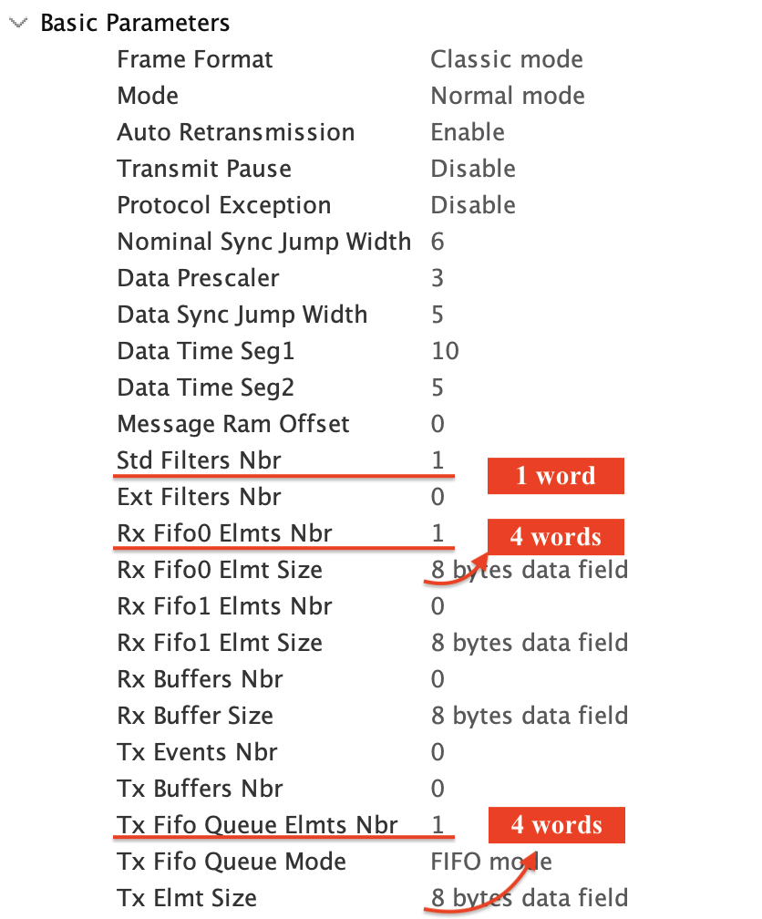
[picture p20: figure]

Figure 2-9: | Parameters for RAM
Offset | Figure 2-10: | FDCAN Message RAM Offset

From which follows:
- FDCAN 1: Message Ram Offset = 0
- FDCAN 2: Message Ram Offset = 9
- FDCAN 3: Message Ram Offset = 18

In other words, for each CAN bus I will use 9 words in my RAM: so I allocate the first 9 words (0 to 8) to bus 1, the second 9 words (from 9 to 17) to bus 2, the third 9 words (from 18 to
26) to bus 3.

### 2.3.6 Damiao motor commands

As the actuators are bought, the commands are coded in the firmware and are predefined by the motor provider. For simplicity, I summarized the data field of each command in the following table:

Command | Data Field (Bytes 07) | Description
enable | [0xFF, 0xFF, 0xFF, 0xFF, 0xFF, 0xFF, 0xFF, 0xFC] | Enable motor
disable | [0xFF, 0xFF, 0xFF, 0xFF, 0xFF, 0xFF, 0xFF, 0xFD] | Disable motor
set_zero_position [0xFF, 0xFF, 0xFF, 0xFF, 0xFF, 0xFF, 0xFF, 0xFE] | Set current position to zero
request | [0x00, 0x00, 0x00, 0x00, regID, 0x33, ID_MSB, ID_LSB] Read position register
mit | [QH, QL, dQH, dQL_KpH, KpL, KdH, KdL_TauH, TauL] | MIT-mode command
Table 2-5: | Byte-wise structure of the 8-byte CAN data fields

The request command will make the motor send back an 8-byte CAN frame in which bytes 47 contain the requested value encoded as a 32-bit IEEE 754 float (little-endian). The position is then decoded in the STM32 and sent to the pi as a raw 4-byte binary float.

2 Hardware Design

The MIT mode command sends five control values — desired position q, velocity q˙, torque ⌧ , proportional gain Kp, and derivative gain Kd — packed into an 8-byte CAN data frame. Each value is first clamped to its physical range, then quantised:
uint = round ✓ x xmin

xmax xmin

- (2b 1)◆

where b is the number of allocated bits. The result is packed in big-endian order using a nibble-stuffed layout as shown in the table below:

Byte | Bits | Contents
0 | Q[15:8] | Position high byte
1 | Q[7:0] | Position low byte
2 | dQ[11:4] | Velocity high bits
3 | dQ[3:0] ⌧ 4 | Kp[11:8] 4 bits of velocity + 4 high bits of Kp
4 | Kp[7:0] | Kp low byte
5 | Kd[11:4] | Kd high bits
6 | Kd[3:0] ⌧ 4| ⌧ [11:8] | 4 bits of Kd + 4 high bits of torque
7 | ⌧ [7:0] | Torque low byte
Table 2-6: | MIT-mode 8-byte CAN data layout (big-endian, nibble-stuffed)

### 2.4 Mechanical Design

### 2.4.1 Frame and supports

The frame was designed using 2D plates and aluminum bars to keep it as light, simple, and cost-efficient as possible. Two materials were considered for the plates: CFRP and aluminum. While aluminum plates are cheaper to manufacture (e.g., via waterjet cutting), they are nearly twice as heavy, with densities of ⇢CFRP = 1.55 g/cm³ and ⇢Al = 2.7 g/cm³ .
Given the importance of reducing inertia in a quadruped, the lighter CFRP plates were selected despite their higher cost.

For the electronic components, the main design criteria were weight, space efficiency, and cost. To meet these requirements, a custom in-house 3D-printed support was developed, which allowed a compact and lightweight integration of the boards.

2 Hardware Design

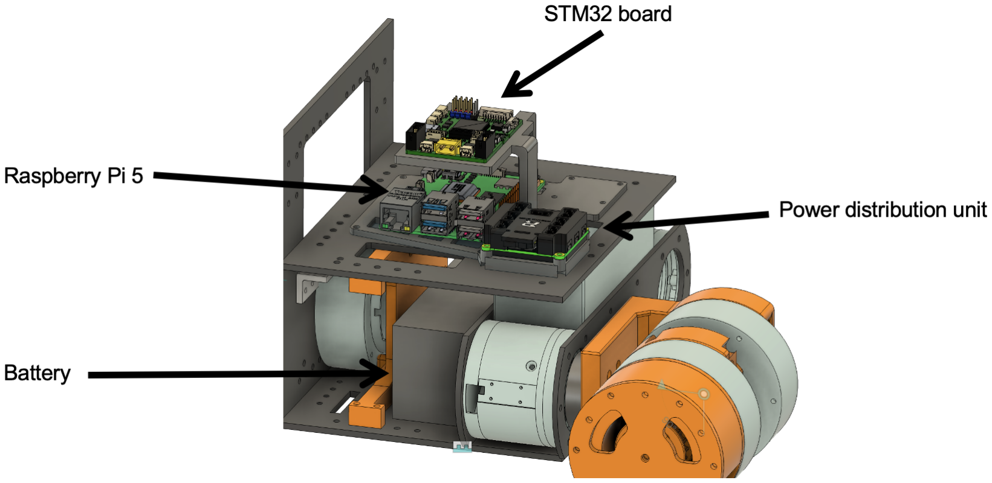
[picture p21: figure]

Figure 2-11: Electronics 3D printed front support

Finally, 3D-printed cover plates were added to enclose the structure, shielding the electronics, battery, and wiring from external impacts.

Figure 2-12: Rendering of the quadruped

### 2.4.2 Leg Design

The first step is to calculate the minimum required torque for each actuator. The chosen scenario is a static trot posture, in which the quadruped balances on two diagonal legs. It is common practice to compute the torque requirements under static conditions and then apply a safety margin typically 25%- to account for dynamic effects. Below, the two free body diagrams (FBD) to calculate the torque of each actuator.

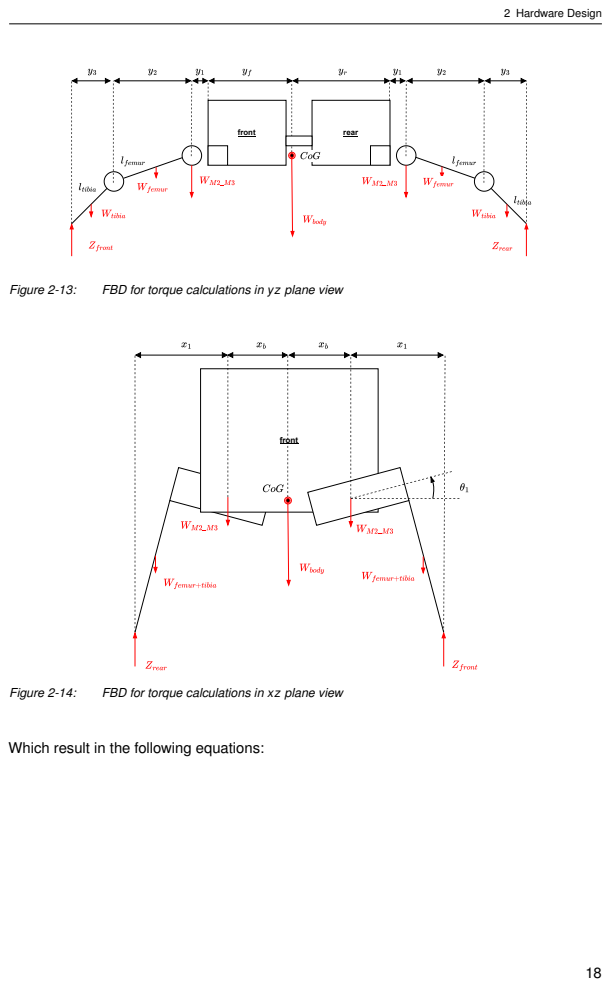
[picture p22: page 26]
2 Hardware Design; front; rear; Figure 2-13:; FBD for torque calculations in yz plane view; Figure 2-14:; FBD for torque calculations in xz plane view

Which result in the following equations:

2 Hardware Design

Zrear =

Wtibia ·

⇣y3
2

⌘
Wfemur ·

⇣y3 + y2
2

⌘
WM3_M2 · (y3 + y2)

Wbody · (y3 + y2 + y1 + yf) WM3_M2 · (y3 + y2 +2y1 + Y)

Wfemur ·

⇣
y3 + y2 +2y1 + Y +

y2
2

⌘
Wtibia ·

⇣
y3 + y2 +2y1 + Y + y2 +

y3
2

⌘ !
(y3 + y2 +2y1 + Y + y2 + y3)

Zfront = Wtot Zrear

T1 = Zfront · x1 +(Wfemur + Wtibia) ·

3
4 · x1 (Wfemur + Wtibia) ·

✓3
4 · x1 +2xb

◆

Wbody · xb WM3_M2 · 2xb + Zrear · (2xb + x1)

T2 = Zfront · (y3 + y2) Wtibia ·

⇣y3
2

+ y2

⌘
Wfemur ·

y2
2

+ Wbody · (y1 + yf)

+ WM3_M2 · (2y1 + Y)+ Wfemur ·

⇣
2y1 + Y +

y2
2

⌘
+ Wtibia ·

⇣
2y1 + Y + y2 +

y3
2

⌘

Zrear · (2y1 + Y + y2 + y3)

T3 = Zfront · y3 Wtibia ·

y3
2

+ Wfemur ·

y2
2

+ WM3_M2 · y2 + Wbody · (2y2 + y1 + yf)

+ WM3_M2 · (y2 +2y1 + Y)+ Wfemur ·

⇣
y2 +2y1 + Y +

y2
2

⌘

+ Wtibia ·

⇣
2y2 +2y1 + Y +

y3
2

⌘
Zrear · (2y2 +2y1 + Y + y3)

The numerical results are presented below as a plot for the waist joint and as graphs for the hip and knee joint. The torque needed for each actuator is the following: 3.1 Nm for waist, 5.4 Nm for hip, 6.3 Nm for knee (considering the 1.5 gear ratio).

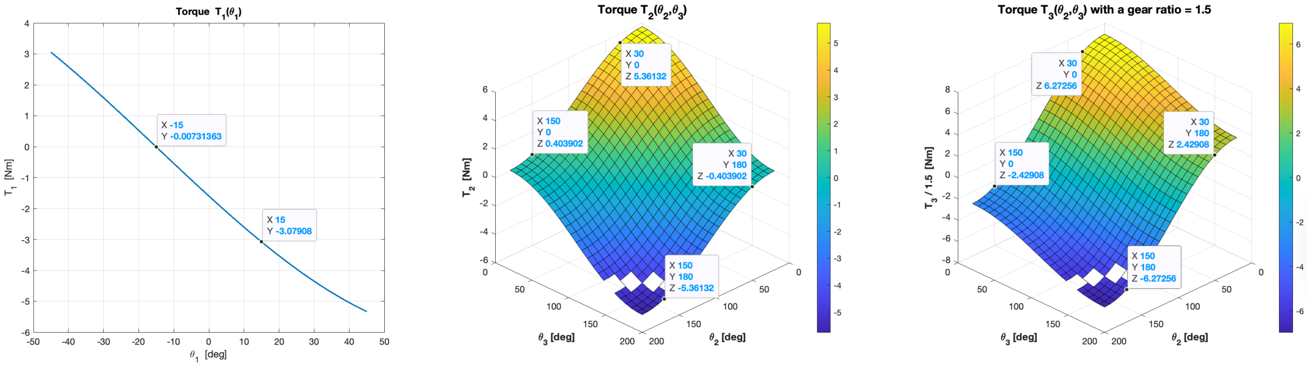
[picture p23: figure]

Figure 2-15: Minimum torque results for legs actuators

From the specifications of the DAMIAO motors available, it follows that the DM6006 has to be chosen for both the hip and the knee. For the knee joint, a belt is added to the design with a gear ratio of 1.5 to make the torque output even higher.

2 Hardware Design

Motor type | Rated torque | Peak torque | Rated current | Peak current | Rated speed
DM-J4310-2EC DM-J6006-2EC | 3 Nm 4 Nm | 7 Nm 12 Nm | 2.5 A 4A | 7.5 A 13 A | 120 rpm 150 rpm
Table 2-7: | Motor specifications from manufacturer datasheets

After selecting the actuators for each joint, the leg was designed using a combination of 3D-printed parts and CFRP plates. The resulting structure has a mass of 0.35 kg without actuators and 1.35 kg with actuators installed.

Part | Material | Mass [kg]
Waist to hip support | Tough PLA | 0.073
Hip to knee support | Tough PLA | 0.050
Gears for toothed belt | Tough PLA | 0.031
Foot structure | Tough PLA | 0.025
CFRP structure | CFRP | 0.100
Table 2-8: | Mass of major leg components

Figure 2-16 illustrates the leg components: actuators are shown in light blue, 3D-printed parts in white, and CFRP plates in black.

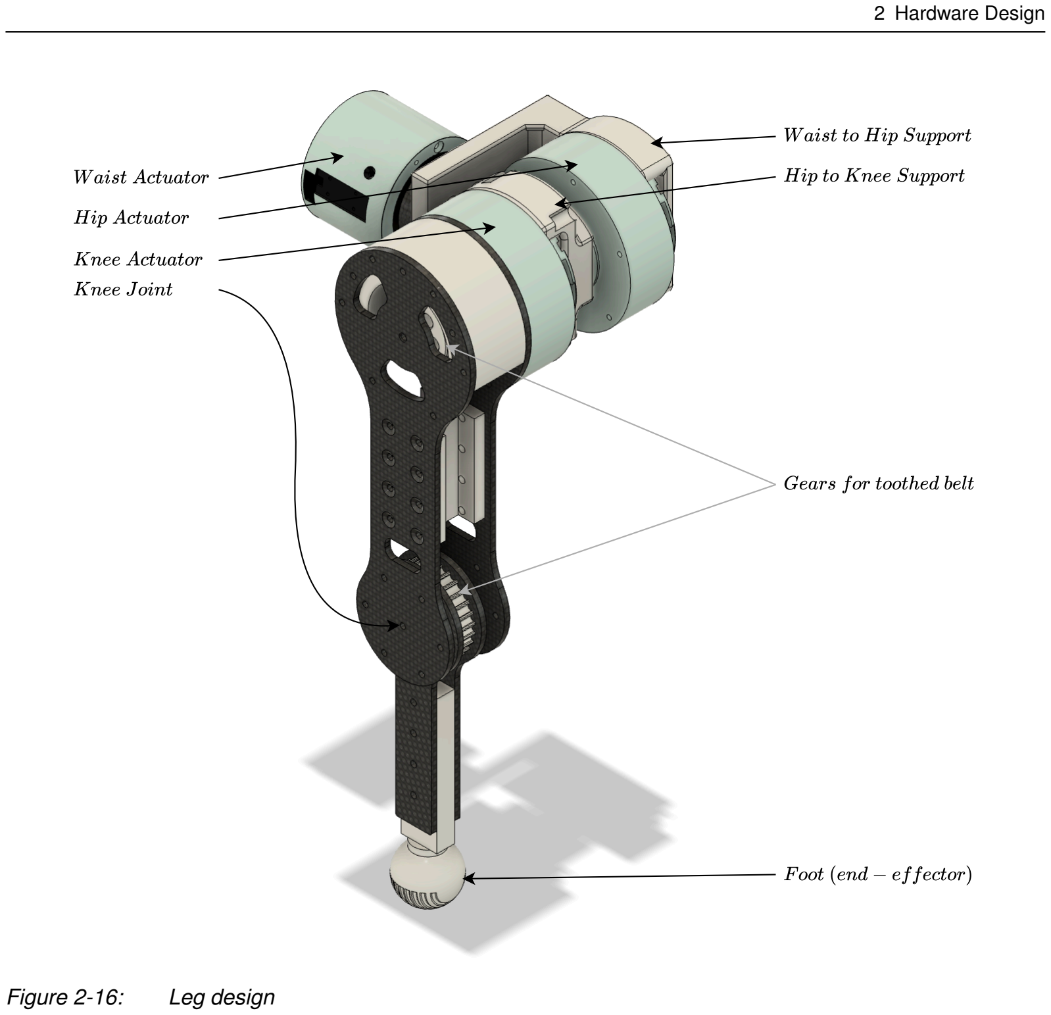
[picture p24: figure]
2 Hardware Design; Figure 2-16:; Leg design

### 2.4.3 Spine Design

Parallel design vs serial design
A parallel design was chosen over a serial one, as it integrates more naturally with the two-body structure of the quadruped. A serial design would have required splitting the chassis into additional segments, since controlling three degrees of freedom would necessitate three distinct bodies connected in series. By contrast, the parallel architecture achieves the same functionality within the existing two-body layout. Furthermore, the parallel design provides higher torque density and improved controllability, at the expense of a reduced range of motion. In this application, however, the available motion range is sufficient, making the trade-off acceptable. In addition, the closed-chain structure of the parallel mechanism increases stiffness and distributes loads across several links, which reduces local deformations and enhances durability under high forces. Locating the actuators closer to the pivot also helps reduce reflected inertia on the moving parts. The drawbacks are a higher sensitivity to manufacturing tolerances, more complex assembly, and a workspace

2 Hardware Design

that can be more limited than in serial designs. Nevertheless, in this quadruped application these disadvantages remain acceptable, as the required workspace is modest and the benefits in torque capacity, rigidity, and controllability are decisive.

Building on this choice, the specific design is inspired by humanoid ankle mechanisms, which also exploit parallel architectures to combine high torque with compactness. In the quadruped, however, an additional degree of freedom was introduced, allowing the front and rear body segments to rotate in opposite directions about the y-axis.

Mechanical Integration
The mechanical integration then focused on three main criteria: minimizing compliance and deformation, avoiding significant increases in overall body length, and ensuring an equal weight distribution between front and rear so that the center of gravity remains as close as possible to the pivot point.

As with the leg design, the first step was to estimate the minimum torque requirements. The same scenario was assumed: a static trot posture in which two diagonal legs support the

Figure 2-17: FBD for spinal torque calculation in yz plane

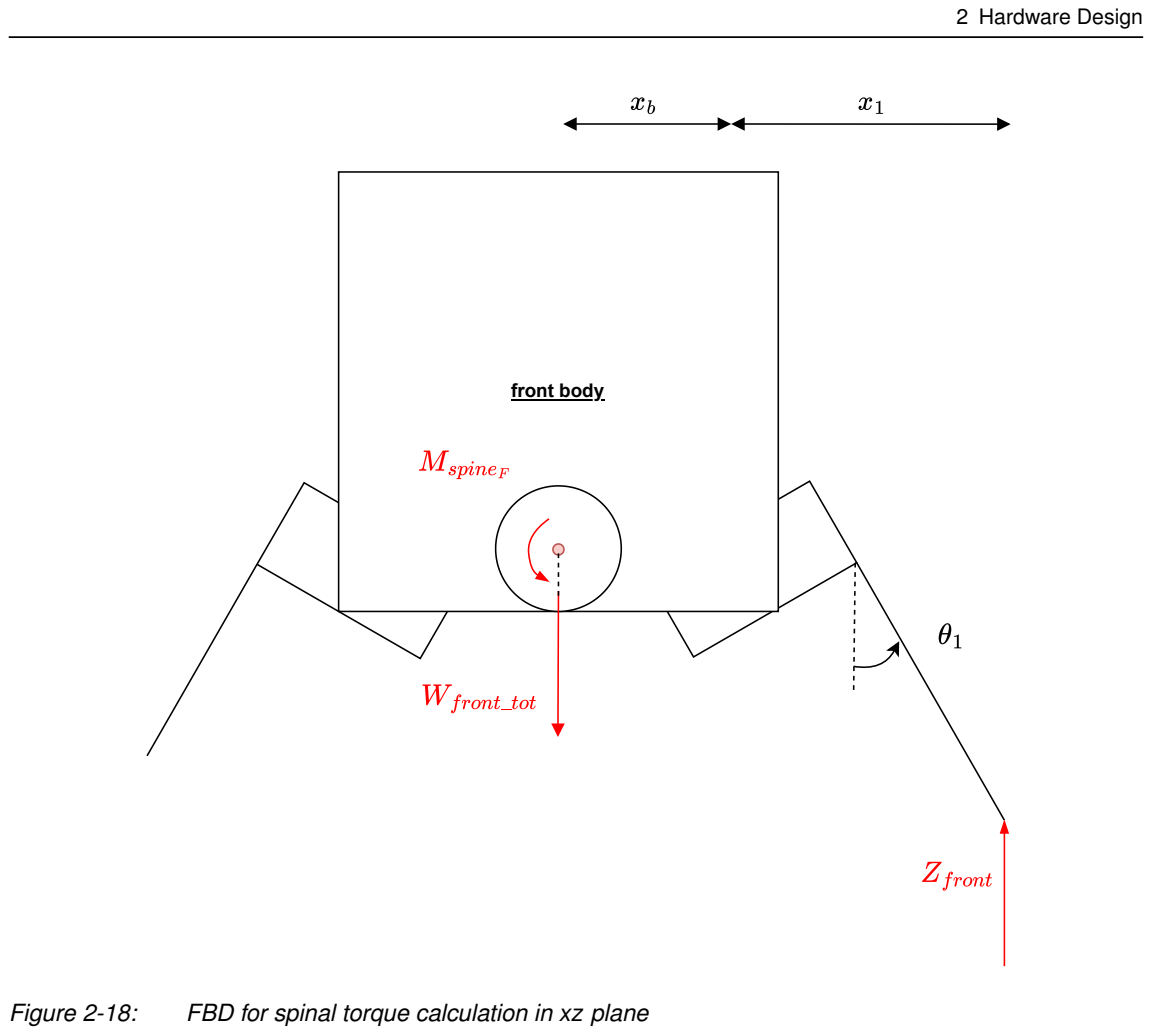
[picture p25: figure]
2 Hardware Design; front body

Figure 2-18: FBD for spinal torque calculation in xz plane

This leads to the following equations: for Figure 2-17, the moment equilibrium is taken at the universal joint (red point), whereas for Figure 2-18, the moment equilibrium is considered at the front actuator (red point).

Fspine,R = Wfront,tot · ycog,uj + Zfront ·

ycog,uj + ycog,hip + y2 + y3

zspine,uj + z2,uj + z2 + z3

Tspine,rear = Fspine,R
2 | · zspine,uj | (we divide by 2 to account for the two actuators)

Tspine,front = Wfront,tot ·

xb + x1

The results are presented as a plot for the front spine joint and as a graph for the rear spine joint. The required torque values are 10.0 Nm for the front spine actuator and 3.5 Nm for the rear spine actuator.

2 Hardware Design

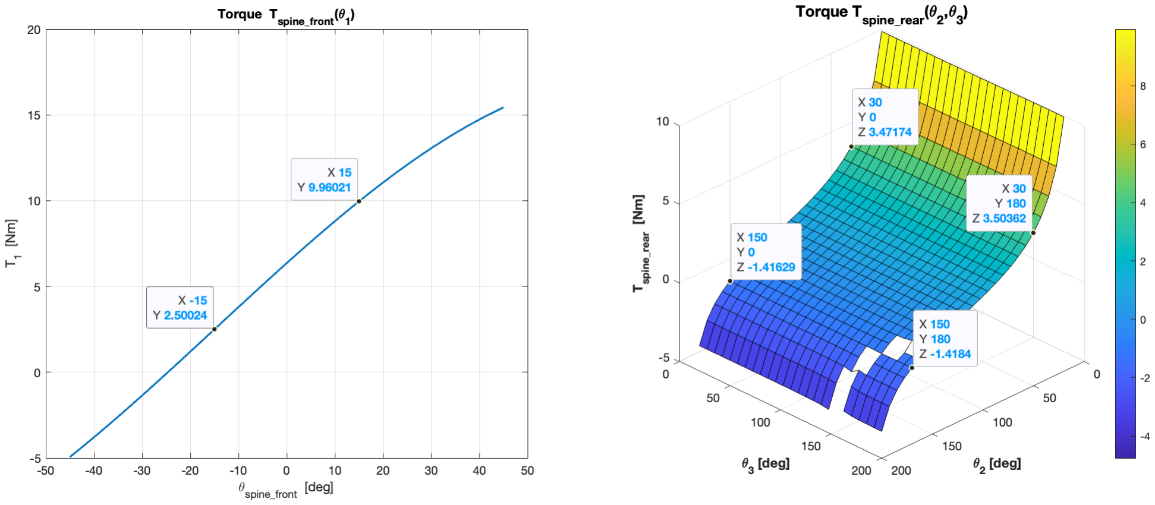
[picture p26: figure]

Figure 2-19: Minimum torque results for spine actuators

Final Design
The final design consists of 3D-printed parts, CFRP plates, steel bar with ball joints, and steel universal joint. The total body length is 56.5 cm, and the center of gravity is positioned close to the rotation center of the universal joint. The spine weighs 0.75 kg without actuators and 1.70 kg with actuators installed.
Part | Material | Mass [kg]
Front actuator support | Tough PLA | 0.055
Spine support | Tough PLA | 0.165
Rear actuator support | Tough PLA | 0.055
Link | Aluminium | 0.050g
Bar | CFRP | 0.012
Universal Joint | Steel | 0.220
Table 2-9: | Mass of the major spine components

The spine support was designed to allow easy replacement with aluminum plates in case greater stiffness is required for future tests. In Figure 2-20 and Figure 2-21, the 3D-printed parts are shown in white, the actuators in light blue, the CFRP bar in black, and the link in grey.

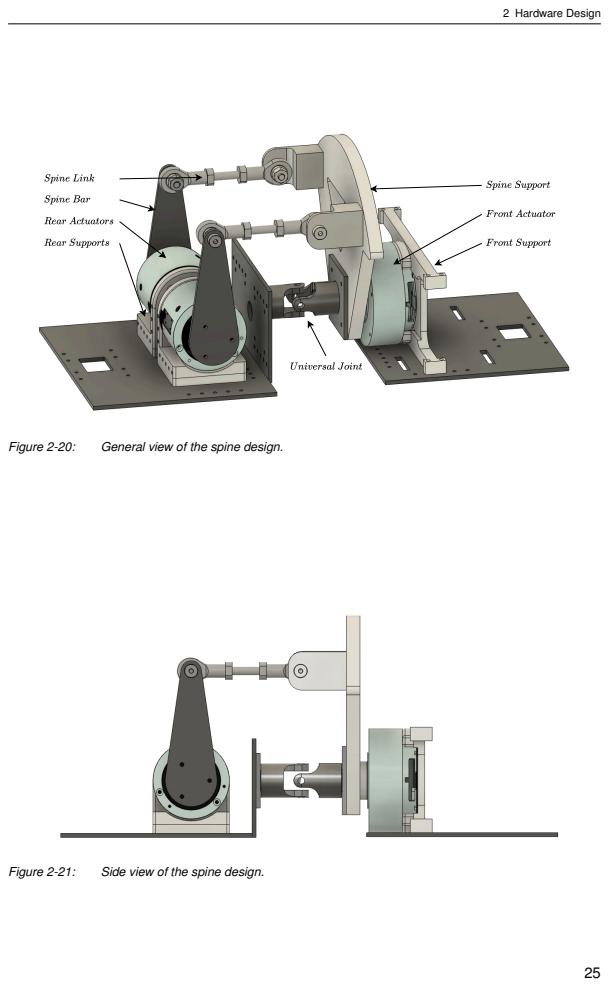
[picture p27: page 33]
2 Hardware Design; Figure 2-20:; General view of the spine design.; Figure 2-21:; Side view of the spine design.

## 3 Control

### 3.1 Approach

Since the main objective of this thesis is to demonstrate that the proposed quadruped design is mechanically robust and controllable, the control algorithms implemented remain at a low level. Specifically:
- Gait control: a predefined closed-loop trot trajectory is executed using position control, with target joint angles computed via inverse kinematics.
- Inclined surface balance: the pitch angle of the spine is adjusted based on feedback from the IMU.

In the present work, the legs and the spine are controlled separately for the sake of simplicity. However, from a control perspective, they are part of a single coupled system: the spine motion directly influences stride length, energy efficiency, and balance, while the legs provide the necessary ground reaction forces to stabilize the body. Future work should therefore focus on integrated control strategies, where the legs and spine are optimized together. For example, a Model Predictive Controller (MPC) could include both the leg joints and the spine joints in its state vector, allowing the optimization to generate coordinated movements. Similarly, Central Pattern Generators (CPGs) or learning-based controllers could be extended to treat the spine as an integral component of locomotion rather than as a separate correction mechanism.

The following sections present the forward and inverse kinematics equations for both the legs and the spine. Subsequently, the formulation of the trot motion and the strategy for balance control are described in detail.

### 3.2 Inverse Kinematics and Forward Kinematics of the leg

In this project, forward kinematics were only used to check if the inverse kinematics were correct. The coordinate frame for each leg is defined with its origin at the center of the waist actuator’s rotating output surface, which is directly screwed to the rest of the leg:

Figure 3-1: Origin of the frame on the leg in its initial position for IK and associated dimensions

The orientation of the coordinate frame of each leg is the following:

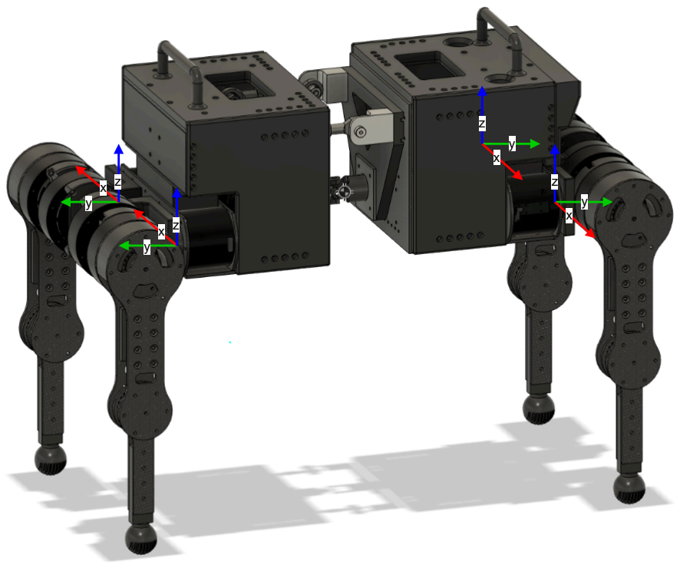
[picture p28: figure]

Figure 3-2: Orientation of the coordinate frames of the four legs

In this case, the parameters have the following values:

d1 = 5.5 cm frame-to-end-effector x-distance
d2 =6 cm frame-to-end-effector y-distance
a2 = 14 cm frame-to-knee joint z-distance

3 Control

a3 = 14.1 cm knee-to-end-effector z-distance

### 3.2.1 Forward Kinematics

In this project, forward kinematics were used primarily to validate the inverse kinematics. The idea was to compute the joint angles through IK for a desired end-effector position, and then apply FK to verify that the reconstructed position matches the desired one:
FK
IK(des_posend_effector)
des_posend_effector = 0.

Several approaches exist to formulate forward kinematics. The most traditional one is the DenavitHartenberg (DH) convention, which parameterizes each joint with four values and builds the transformation step by step. It is compact and widely used in robotics literature, but it can become cumbersome for complex mechanisms with non-standard joint layouts. A more modern and general approach is the Product of Exponentials (POE) formula, which expresses each joint motion as a matrix exponential of its screw axis. This method is well-suited to open kinematic chains. Finally, FK can also be implemented in a purely numerical form, where transformations are composed iteratively using homogeneous matrices or quaternions; this is straightforward to code but less compact analytically.

In this thesis, the POE formulation was adopted, as it provides a consistent and general framework that integrates well with the analytical IK derivation already used for the legs.

Forward Kinematics via Product of Exponentials
As the leg can be modelled as an open-kinematic chain, the forward kinematics are computed using the product of exponentials formula, which requires:
- Definition of screw axes: each joint axis must be expressed as a twist [Si] in 6D space (angular and linear velocity components).
- Home configuration: the end-effector pose M must be defined at the reference position (✓i =0).
- Joint angles: the current configuration is parameterized by the joint values ✓i.

Hence, the forward kinematics are computed with:

T(✓)= e[S1]✓1 · e[S2]✓2 · e[S3]✓3 · M

where:
- [Si] 2 R⁴⇥4 are the screw axis matrices in space frame
- ✓i are the joint angles
- M is the home configuration of the end-effector

3 Control

The home configuration matrix M is:

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
100 | d1
010 | d2

001 a2 + a3

000 1

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
The screw axes in space frame are:

S1 =

100000T
, S2 =
| 01000 d2

T

S3 =

010 d2 0 (a2 + a3)

T

After evaluating the full transformation matrix T(✓) 2 SE(3), the position of the end-effector in 3D space is obtained from the translation part (last column):

Positionend-effector =

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
### 3.2.2 Inverse Kinematics

There are two main approaches to solving inverse kinematics: numerical and analytical. Numerical methods (e.g., NewtonRaphson, Jacobian-based solvers) are general and can handle almost any kinematic structure, even when the geometry is complex or redundant. They are also relatively easy to implement. However, they require iterative computation, which increases computational cost, and may converge slowly or get stuck in local minima if the initial guess is poor.

Analytical methods, on the other hand, exploit the geometry of the mechanism to derive closed-form equations for the joint angles. When such a solution exists, it provides exact results with very low computation time, which is particularly advantageous for real-time control. The downside is that analytical solutions are only possible for relatively simple kinematic chains and become cumbersome to derive as the number of joints and complexity of the geometry increases.

3 Control

In this project, both methods were tested at the beginning. Ultimately, the analytical approach was chosen and the inverse kinematics function was hard-coded, in order to minimize computing time and ensure performance during real-time control.

For a given leg, let the desired foot position be (px, py, pz). For simplicity, the reference frame is aligned with the axes of the hip and knee actuators, introducing a translation of +d2 along the y-axis. As a result, the transformed foot position becomes

Figure 3-3: Quadruped with end-effector desired position for front right (FR) leg

Then the hip (abduction) angle ✓1 is:

✓1 = || |↵|

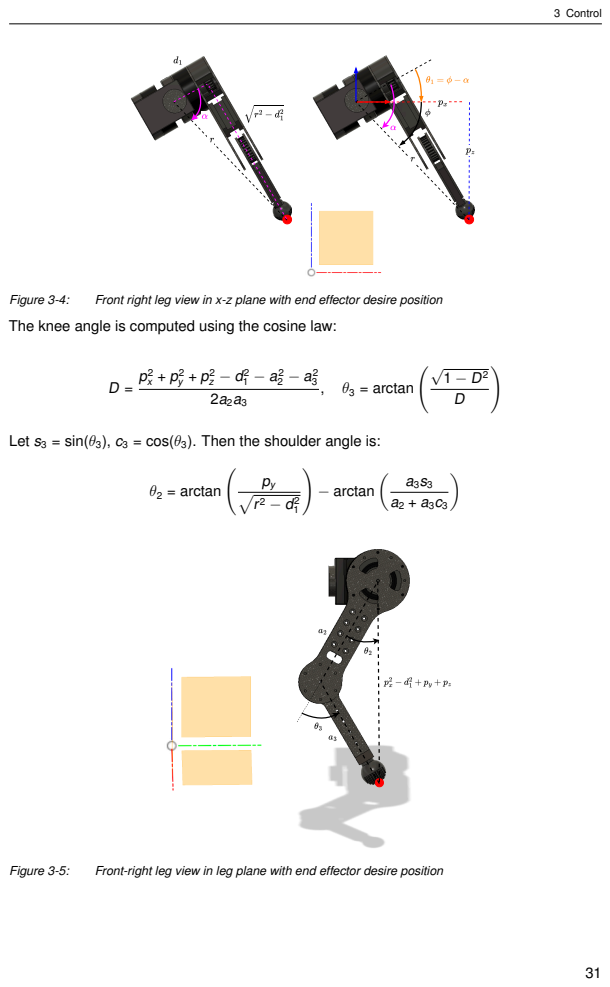
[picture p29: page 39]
3 Control; Figure 3-4:; Front right leg view in x-z plane with end effector desire position; , ✓3 = arctan p1  D²; ✓2 = arctan;  arctan ✓ a3s3; Figure 3-5:; Front-right leg view in leg plane with end effector desire position

The knee angle is computed using the cosine law:

Let s3 = sin(✓3), c3 = cos(✓3). Then the shoulder angle is:

3 Control

For legs (1, 2) (front left and rear right), the angles are negated:

✓1_new = ✓1, ✓2_new = ✓2, ✓3_new = ✓3

Explanation for the negations:
The joint angle ✓1 is negated for leg 1 to produce a waist movement symmetric to that of leg
0. It is also negated for leg 2 because the rotational axis of its waist actuator, following the right-hand rule, is oriented opposite to that of leg 0. The angles ✓2 and ✓3 are negated for leg 1 because their actuator rotation directions are reversed compared to leg 0. For leg 2, ✓2 and ✓3 are negated to enforce a mirrored posture with respect to the front legs, such that the knee bends in the opposite direction.

### 3.3 Inverse Kinematics and Forward Kinematics of the spine

### 3.3.1 Inverse Kinematics

The spine is inspired by the ankle design of humanoids, it is a parallel kinematics mechanism. [Zho-2023] presents an extensive kinematic analysis of this design, and the inverse kinematics derivation is also detailed below. The frame is different than of the legs’ inverse

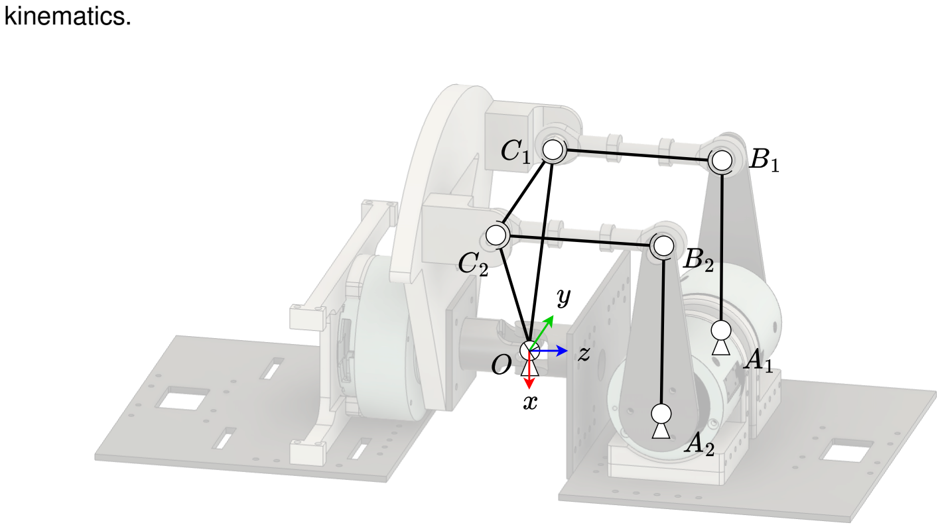
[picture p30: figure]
kinematics.

Figure 3-6: Spine diagram

It always holds true that:

## krCi rBi

k = lrod, for i = 1, 2,

3 Control

Solving the above equations we get to: let theta be the motors’ position,

✓i = arcsin

bc +

pb²c² (a² + b²)(c² a²)

a² + b²

!
,

where,

a = {rCi rAi

}x,
b = {rAi rCi

}z,
c = l

2
rod l

2
bar krCi rAi

k²

2lbar

,

lbar =

0

rBi ⁰
rAi
= {⁰
rO ⁰
rCi

}x = 80 mm,

lrod =

0

rCi ⁰
rBi
= {⁰
rO ⁰
rAi

}z = 80 mm,

lspacing =

0

rA1 ⁰
rA2
=
0

rB1 ⁰
rB2
=
0

rC1 ⁰
rC2
= 122 mm,

rBi = rAi + Ry(✓i)

0
rBi ⁰
rAi
,

rCi = xrot

0
rCi

,
rAi = ⁰
rAi

,

xrot = Ry(q

pitch
ankle) Rx(qroll
ankle),

Rx()=

2
6
6
6
6
4
1 | 0 | 0

0 cos sin

0 sin cos

3
7
7
7
7
5

, Ry()=

2
6
6
6
6
4

cos 0 sin

0 | 1 | 0

sin 0 cos

3
7
7
7
7
5

3 Control

For this quadruped the dimensions are:

0
rAi =

2
6
6
6
6
4

0

0.061

0.081

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
0.061

0.081

3
7
7
7
7
5

0
rBi =

2
6
6
6
6
4

0.08

0.061

0.081

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
0.08

0.061

0.081

3
7
7
7
7
5

0
rCi =

2
6
6
6
6
4

0.08

0.061

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
0.08

0.061

0

3
7
7
7
7
5

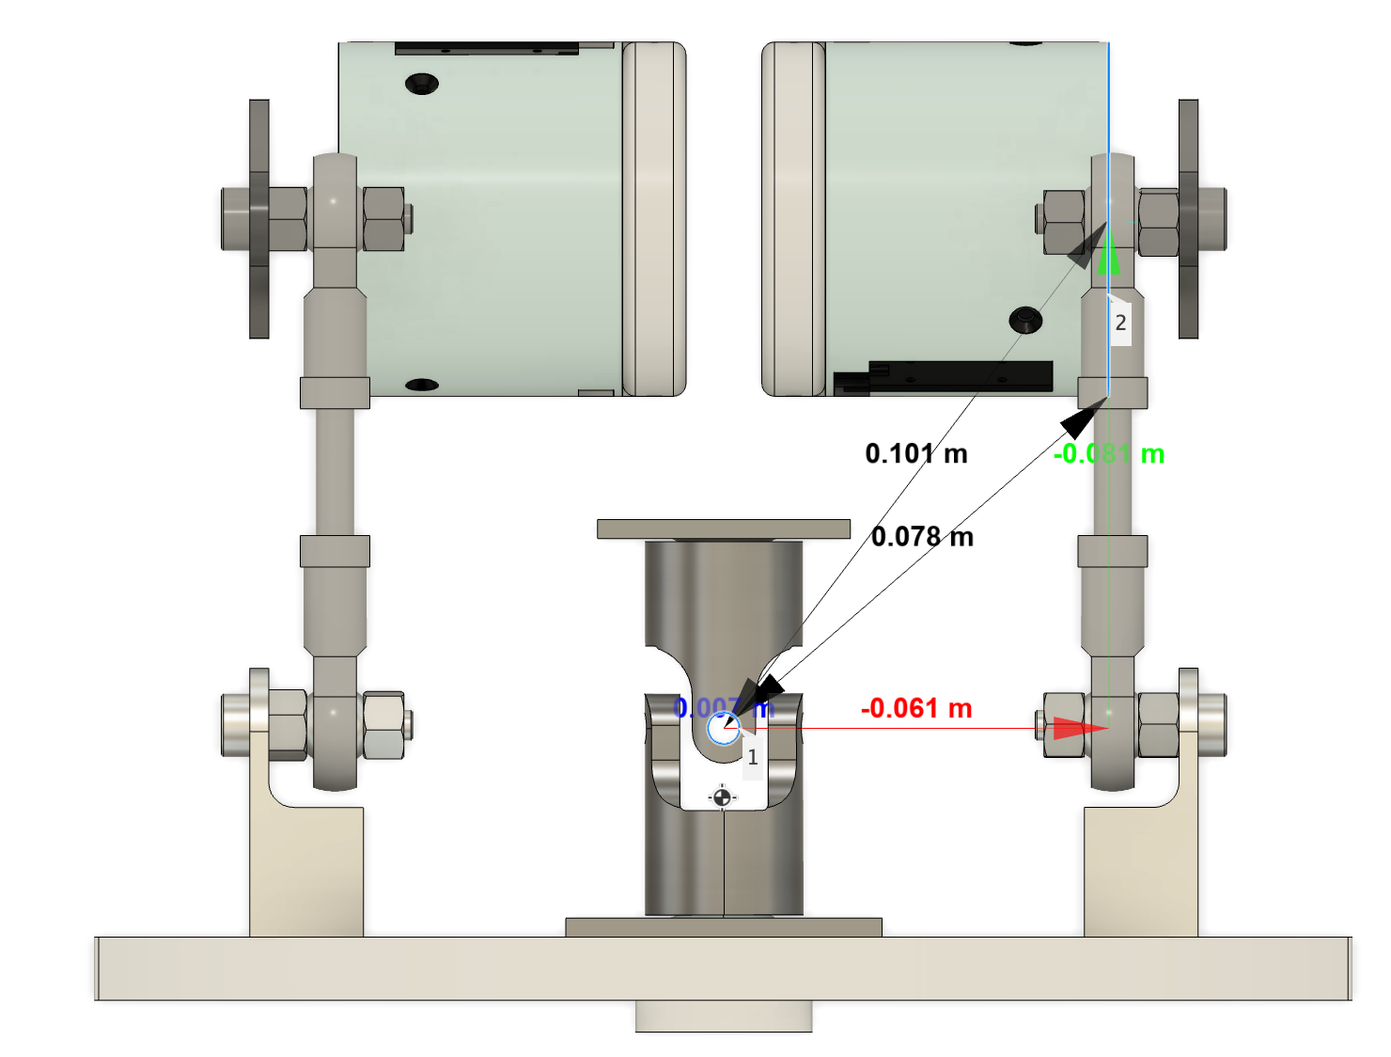
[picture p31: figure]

(a) x-z plane | (b) y-z plane
Figure 3-7: | Spine dimensions in x-z plane and y-z plane

3 Control

### 3.3.2 Forward Kinematics

The forward kinematics are solved using the Newton-Raphson method estimating the error with the inverse kinematics:

xk+1

c = xk

c
Jc(xk
c)

1
fik (xk
c) ✓ref
, | (3-1)

Jc = JG 2 R²⇥2
, | (3-2)

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
0 | 0
0 | 0
0 | 0

cos ↵ 0

0 1

sin ↵ 0

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
2 R⁶⇥2
, | (3-3)

J = J1
✓ Jx 2 R²⇥6
, | (3-4)

Jx =

2
6
4

r>
rod1
rC1 ⇥ rrod1

>

r>
rod2
rC2 ⇥ rrod2

>

3
7
5

2 R²⇥6
, | (3-5)

J✓ =

2
6
4

s11 ·

rbar1 ⇥ rrod1

0

0 | s21 ·
rbar2 ⇥ rrod2

3
7
5

2 R²⇥2
, | (3-6)

rbari = rBi rAi

, | rrodi = rCi rBi
, | (3-7)

s11 =

010
, s21 =

0 10
. | (3-8)

Once the inverse and forward kinematics were derived, the motion strategies for gait generation and balance control could be formulated. These are presented in the following two sections.

3 Control

### 3.4 Gait: trot equations

Trot Parameters
The foot trajectory for each leg is generated over a periodic stride using the following configurable parameters:
- Tstride: stride period [s]
- B: duty factor (stance ratio), B 2 (0, 1)
- i: phase offset for leg i 2 {0, 1, 2, 3}
- L: stride length [m]
- h: apex height of the swing trajectory [m]
- x0: lateral position of the foot [m]
- z0: constant foot height during stance [m]

Normalized Time and Phase Offset
For each leg i, the current time t is normalized over the stride period and shifted by a leg-specific phase:

t

¯

i = mod ✓ t

Tstride

+ i,1◆
- Tstride

Let Tstance = B · Tstride. The motion is separated into:

Stance: t

¯
i < Tstance, Swing: t

¯
i Tstance

Trajectory Equations
The x-coordinate is constant per leg:

xi =

8
<
:
x0 | if leg i 2 {0, 3}
x0 | if leg i 2 {1, 2}

A smooth quintic interpolation function is used:

smooth(u) = 10u³ 15u⁴ +6u⁵
| , u 2 [0, 1]

Stance Phase (t

¯
i < Tstance): Let u = t

¯
i

Tstance . Then:

3 Control

yi =

8
<
:

+

L
2 L · smooth(u)

if leg i 2 {0, 1}
L
2 L · smooth(u)

if leg i 2 {2, 3} , zi = z0

Swing Phase (t

¯
i Tstance): Let u = t

¯
iTstance
TstrideTstance . Then:

yi =

8
<
:

+

L
2 + L · smooth(u)

if leg i 2 {0, 1}
L
2 + L · smooth(u)

if leg i 2 {2, 3}

zi = z0 +

h
1.875 ·
30u² 60u³ + 30u⁴

This formulation ensures a continuous trajectory for the foot in both stance and swing phases with smooth velocity and acceleration transitions.

Figure 3-8: Foot trajectory over time (axis have same scale)

### 3.5 Balance on an inclined surface

The goal is to get a part of the body, either front or rear, to remain horizontal on an inclined plane; for this we have to give the spine a pitch angle equal to the angle of the inclined plane. Depending on which part of the body we want to keep horizontal, the angle of the inclined plane is calculated in different ways as I will show in the next paragraphs.

3 Control

Figure 3-9: Diagram of the quadruped on an inclined plane

### 3.5.1 Rear body balance

For the rear body, the desired pitch angle for the spine is the angle of the IMU, ↵spine = ↵imu as shown by the figure below:

front body

rear body

Figure 3-10: Rear body balance

### 3.5.2 Front body balance

However, in the case where the front body should be kept horizontal, the IMU angle will not be the angle of the inclined plane, therefore, a way through this is ↵spine+= ↵imu, however a gain needs to be added as otherwise the quadruped overshoots and becomes exetremely unstable: ↵spine+= kpspine · ↵imu (in my case kpspine = 0.001

3 Control

rear body

front body

Figure 3-11: Front body balance

### 3.5.3 Legs

The objective is to maintain the same contact point on the ground plane while the spine rotates. This is done by expressing the original foot position pO
foot (in the original leg frame
O) with respect to the new rotated leg frame O0

, which is centered at the same pivot point. The point rotates by an angle ↵pitch around the x-axis, and then is translated into the leg’s coordinate frame by subtracting the offset between the pivot and the leg base frame. The transformation is given by:

pO0
foot = R x

(|↵pitch|) · pO
foot O

where the 3D rotation matrix Rx(↵) around the x-axis is:

R x

(↵)=

2
6
6
6
6
4
1 | 0 | 0

0 cos(↵) sin(↵)

0 sin(↵) cos(↵)

3
7
7
7
7
5

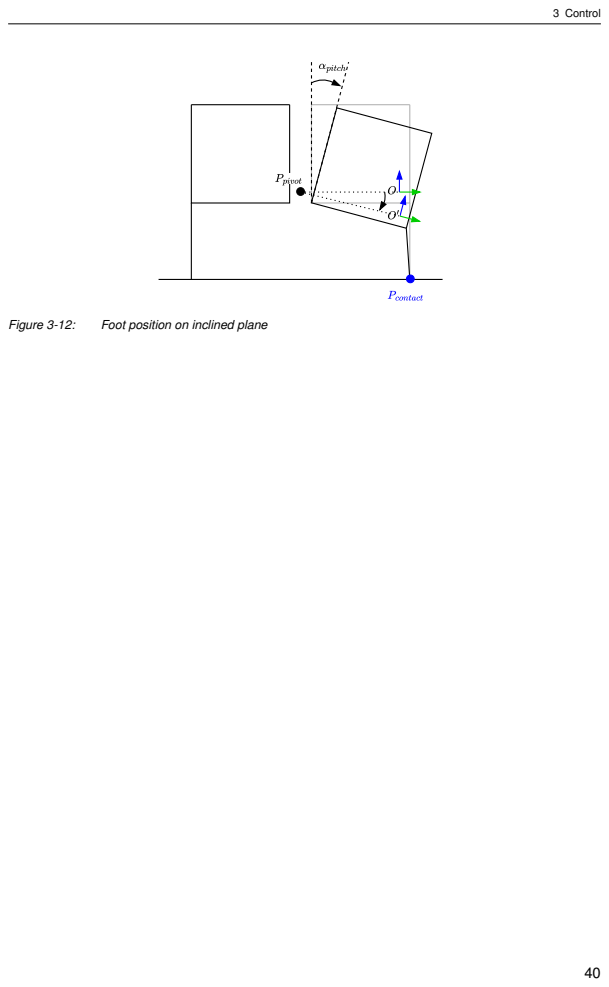
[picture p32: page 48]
3 Control; Figure 3-12:; Foot position on inclined plane

## 4 Software Design

### 4.1 Introduction

The software is designed in a modular way using ROS2, allowing the physical robot to be replaced by a MuJoCo simulation without altering the control logic. Two categories of nodes are defined: interface nodes and control nodes.

The interface nodes are responsible for translating control commands to the hardware or the simulator. Specifically, leg_command_node communicates with the real quadruped via USB, while mujoco_node executes the equivalent commands in the MuJoCo simulation.

Control nodes generate the desired motion and send actuator positions to one of the two interface nodes. In this thesis, three control nodes were implemented: hardware_check.cpp, trot_node.cpp, and spine_pitch_inclined_plane_node.cpp. These are described in

"[FRW] [FRH] [FRK] ... [SF] [SRR] [SRL] "

Figure 4-1: ROS2 nodes graph

### 4.2 Joints Notation

Each time an array refers to the four legs, the order of the legs is: front right (FR), front left (FL), rear right (RR), and rear left (RL). If the array also contains the joints of each leg, the order of the joints is: waist (W), hip (H), and knee (K). The spine values, when present, are always placed last, with the joint order: front (F), rear right (RR), rear left (RL).

Table 4-1 summarizes the arrangement: each row corresponds to a joint type, and each column corresponds to a leg or spine element.

| FR (col=0) | FL (=1) | RR (=2) | RL (=3) | S (=4)
W (line=0) | FR–W | FL–W | RR–W | RL–W | S–F
H (=1) | FR–H | FL–H | RR–H | RL–H | S–RR
K (=2) | FR–K | FL–K | RR–K | RL–K | S–RL
Table 4-1: | Joint and leg order in arrays.

The next section will explain the code of each node, in the following order:

4 Software Design

- leg_command_node.cpp
- mujoco_node.cpp
- hardware_check.cpp
- trot_node.cpp
- spine_pitch_inclined_plane_node.cpp

### 4.3 ROS 2 architecture

### 4.3.1 leg_command_node.cpp

This node receives commands in ’human language’ through the leg_command_topic and translates them into USB messages sent to the STM32s.

The topic to which commands should be published is leg_command_topic, using the format "leg,joint,command" (std_msgs/msg/String). For clarity, leg and joint numbering starts at 1, as it is more intuitive to refer to the first leg rather than leg zero. For example:

1, 1 = front right waist joint, 2, 3 = front left knee joint, 4, 2 = rear right hip joint.

The command field can take one of the following values:
- enable
- disable
- request
- set_zero_position
- mit,kp,kd,pos,vel,tau

Examples:
- "1,2,enable" enables the hip motor of the front right leg.
- "3,1,set_zero_position" sets the current position as zero for the waist motor of the rear right leg.
- "4,1,request" requests the current position of the waist actuator of the rear left leg.
- "2,3,mit,6,0.6,0,0" sets the knee motor of the front left leg to MIT control with kp =6, kd = 0.6, position = 0 rad, angular velocity = 0 rad/s, and torque = 0 Nm.

This structure allows new control nodes to be added easily to send commands. For the MuJoCo simulation, the format of the message published to actuator_goal_rad is even simpler (cf. next section).

4 Software Design

Sending individual commands from the terminal
One of the main reasons for designing this node to send only a single command at a time rather than sending the positions of all 15 actuators at once, as done in the mujoco_node, is to enable direct control of any specific motor from the terminal. This approach allows testing or debugging individual actuators without modifying the control code.

For example, the following command sends an MIT control instruction to the hip motor of the front left leg:

ros2 topic pub -1 /leg_command_topic std_msgs/msg/String \
"data: ’2,2,mit,4.0,0.4,0,0,0’"

Code structure and message flow
The leg_command_node.cpp is designed as a modular pipeline: each function has a single role. When a command message is published to leg_command_topic, it goes through four steps (Figure 4-2):
1. Message reception: The ROS 2 subscriber callback calls handle_cmd(), which parses the incoming "leg,joint,command" string and extracts numeric values and the command type.
2. Payload preparation: One of three functions builds the 8-byte CAN payload: prepare_payload_cmd() (enable/disable/zero position), prepare_payload_mit() (MIT control), or prepare_payload_request() (register read).
3. USB frame assembly: The CAN payload is passed to build_frame() to add CAN ID/bus, then build_usb_frame() wraps it into the 14-byte USB packet.
4. USB transmission: send_usb() writes the packet to the correct serial port (/dev/ttyACM0 or /dev/ttyACM1) and optionally waits for a reply.

This modular design means adding a new command type only requires creating a new payload preparation function without changing the rest of the process. A collapsed version of the code is presented in the Appendix A.1.

Execution flow diagram:

4 Software Design

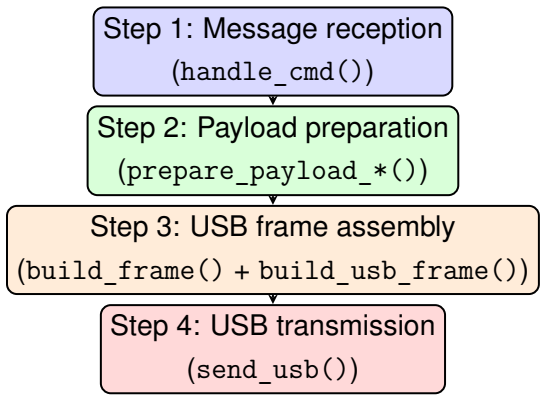
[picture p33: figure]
Step 1: Message reception (handle_cmd()); Step 2: Payload preparation (prepare_payload_*()); Step 3: USB frame assembly (build_frame() + build_usb_frame()); Step 4: USB transmission (send_usb())

Figure 4-2: Function call sequence in leg_command_node.cpp

### 4.3.2 mujoco_node.cpp

This node runs the MuJoCo physics simulation when launched, where each joint is controlled to the requested position by the topic actuator_goal_rad.

It subscribes to the topic actuator_goal_rad (type: std_msgs/msg/Float64MultiArray), which carries the desired joint positions for the four legs and the spine, in the same leg/joint ordering convention used throughout the project. The received positions are stored in the array actuator_goal_rad[joint][leg/spine].

The node can operate in two modes: torque control or position control. - In torque control mode, it computes joint torques using a custom PD controller based on measured positions and velocities from the simulation. - In position control mode (used for most of this thesis), the desired joint positions from actuator_goal_rad are sent directly to the simulation actuators.
I chose to keep the torque control functions in the codebase (get_cur_actuator_pos(), get_cur_actuator_vel(), computePDtorque_fixed()) so that switching to torque mode in the future only requires uncommenting a few lines in the controller() function, which orchestrates all major control steps.
The node also publishes simulated IMU measurements to the topic imu_data (type: sensor_msgs/msg/Imu), which are primarily used for spine control during balance experiments.

Code structure and message flow for position control:
1. Message reception: Subscription callback to actuator_goal_rad updates the actuator_goal_rad array.
2. Command sending: The desired positions are written directly to d->ctrl[] using send_cmd_pos().

4 Software Design

Code structure and message flow for torque control:
1. Message reception: Subscription callback to actuator_goal_rad updates the actuator_goal_rad array.
2. State acquisition: get_cur_actuator_pos() and get_cur_actuator_vel() read the simulated joint states from MuJoCo sensors.
3. Control computation: computePDtorque_fixed() calculates the torque for each joint from PD gains and position/velocity errors.
4. Command sending: The torques are written to d->ctrl[] using send_cmd_-torque().

Again, a collapsed structure of the code is presented in the Appendix A.1.

Execution flow diagram for position control:

Step 1: Message reception
(start_subscription())
Step 2: Command sending
(send_cmd_pos())

Figure 4-3: Function call sequence for position control in mujoco_node.cpp

Execution flow diagram for torque control:

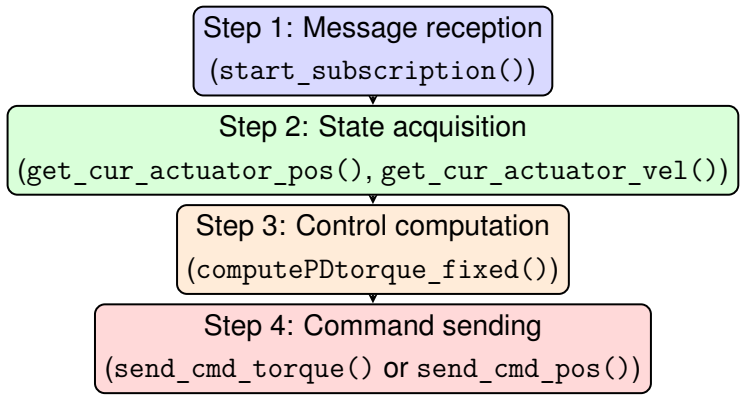
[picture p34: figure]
Step 1: Message reception (start_subscription()); Step 2: State acquisition (get_cur_actuator_pos(), get_cur_actuator_vel()); Step 3: Control computation (computePDtorque_fixed()); Step 4: Command sending (send_cmd_torque() or send_cmd_pos())

Figure 4-4: Function call sequence in mujoco_node.cpp

### 4.3.3 hardware_check.cpp

This node provides a simple routine for setting all the actuators’ mechanical position to zero.

4 Software Design

On startup it zeroes all joints and drives them to a no-torque MIT state, then iterates leg-by-leg in the typical order FR, FL, RR, RL, S (legs 1 to 5) every 5s to zero the legs joints again (so the user can choose the mechanical zero) and apply an MIT hold at 0 rad (to keep the chosen position). All commands are published to leg_command_topic (std_-msgs/msg/String) using the same "leg,joint,command" format as the other nodes.

Default startup behavior (on node creation):
1. Enable all motors without torque (do_startup_sequence(6)): for each leg 1...5 and joint 1...3: disable ! enable ! set_zero_position ! mit,0,0,0,0,0 (no torque).
2. Per-leg initialization (every 5s in order FR, FL, RR, RL, S): set_zero_position ! mit,1.0,0.1,0,0,0 for joints 1, 2, 3 of that leg.

Typical usage. Launch the node and use the 5s window to manually place the front right leg at the desired zero (cf. IK leg). At t = 5s the node records zero and applies a gentle hold; the next 5s window is for the front left, then rear right, rear left, and finally the spine.

Available debug helpers (uncomment to use):
- send_mit_cst_test(): periodically sends mit,5,0.5,0,0,0 to all joints (attachable to a 50 ms wall timer).
- send_position_requests(): requests the position of all 15 joints.
- send_disable_all(): disables every actuator.

Again, a collapsed structure of the code is presented in the Appendix A.1

Execution flow diagram of the startup sequence:

4 Software Design

Figure 4-5: Function call sequence in hardware_check.cpp

### 4.3.4 trot_node.cpp

This control node computes the trot equations, from which it calculates the joints’ position with IK and finally publishes the commands to an interface node.

For clarity, the implementation is organized into three parts: trot equation, IK, and the controller (which publishes).

Collapsed view of the file (classes and entry point):
1 | double xyz_goal_mm[3][4] = {0};
2 | double legs_actuator_goal_rad [3][4] = {0};
3 | double spine_actuator_goal_rad[3] = {0};
4 | class TrotEquations { /* compute_xyz_goal_pos () , stance () , swing () , ...
*/ };
5 | class IKSolver | { /* compute_IK () , link lengths d1 ,a2 ,a3 */ };
6 | class SpineEquations{ /* compute_spine_actuator_goal () -> zeros */ };
7 | class GaitController{ /* update (): trot -> IK -> spine */ };
8 | class MinimalPublisher : public rclcpp::Node { /* timers + publishers */
| };
9 | int main( int argc , char * argv[]) { /* spin MinimalPublisher */ }

Step-by-step process of trot_node.cpp:

4 Software Design

Blue = ROS control Orange = computation Yellow = data arrays Green = publish topics

1) Trot equations
TrotEquations computes for each leg the coordinates of the end-effector desired position.

It keeps all the gait parameters in one place (stride period, duty factor, swing height, stride length, leg phase offsets, base height, ...). At each control step, one call to compute_xyz_-goal_pos() refreshes the four foot targets. Internally it decides whether a leg is in stance or swing and then fills x, y, z using the small helper functions. A collapsed version of the code is presented in the Appendix A.1.
Call flow inside compute_xyz_goal_pos():

4 Software Design

2) Legs & spine actuator positions (IK)
IKSolver::compute_IK() turns the foot targets into joint angles [waist, hip, knee] for each leg. SpineEquations is a small class kept for future experiments; for now its function simply sets the three spine goals to zero. A collapsed version of the code is presented in the Appendix A.1.
3) Controller and publishers
GaitController::update() calls the three steps in order: trot equations ! IK ! spine. In MinimalPublisher, this update runs every 10 ms and, in the same timer, publishes the 15 actuator goal positions to actuator_goal_rad so you can see the whole set of actuator positions in one line at each time step. A second timer publishes MIT commands to leg_command_topic every 30 ms. The gains use a ramp that goes from 0% to 100% over 10 s to keep bring-up smooth. A collapsed version of the code is presented in the Appendix A.1

Timing overview:

time

every 10 ms: update() + publish actuator_goal_rad

every 30 ms: send_MIT_cmd() (kp,kd ramp over 10 s)

### 4.3.5 spine_pitch_inclined_plane_node.cpp

This control node keeps either the front or the rear of the robot horizontal while standing on an inclined plane.

A single flag routes almost all computations:

int incline_front_or_rear = 1;

8
<
:

0: keep front horizontal
1: keep rear horizontal

4 Software Design

The controller uses the IMU pitch and the current spine positions to compute spine and leg targets that satisfy the chosen constraint.

Collapsed view of the file (classes and entry point):
1 | double xyz_goal_mm[3][4] = {0}; | | // foot xyz goals (FR , FL ,
| RR , RL)
2 | double legs_actuator_goal_rad [3][4] = {0}; | // [waist , hip , knee ] per
| leg
3 | double spine_actuator_goal_rad[3] | = {0}; | // [front , rear -right , rear
- left ]

4
5 | class leg_kinematics | { /* inclined foot pose from IMU & offsets
| */ };
6 | class IK_leg | { /* leg IK -> legs_actuator_goal_rad
| */ };
7 | class IK_spine | { /* spine IK -> spine_actuator_goal_rad
| */ };
8 | class FK_spine | { /* FK from spine angles ( consistency /
| estimation ) */ };
9 | class BalanceController{ /* orchestrates front / rear balance logic
| */ };

10
11 | class spine_pitch_inclined_plane_node : public rclcpp::Node { /* I/O +
| timers */ };
12 | int main( int argc , char ** argv) { /* spin node */ }

Step-by-Step Process of spine_pitch_inclined_plane_node.cpp

4 Software Design

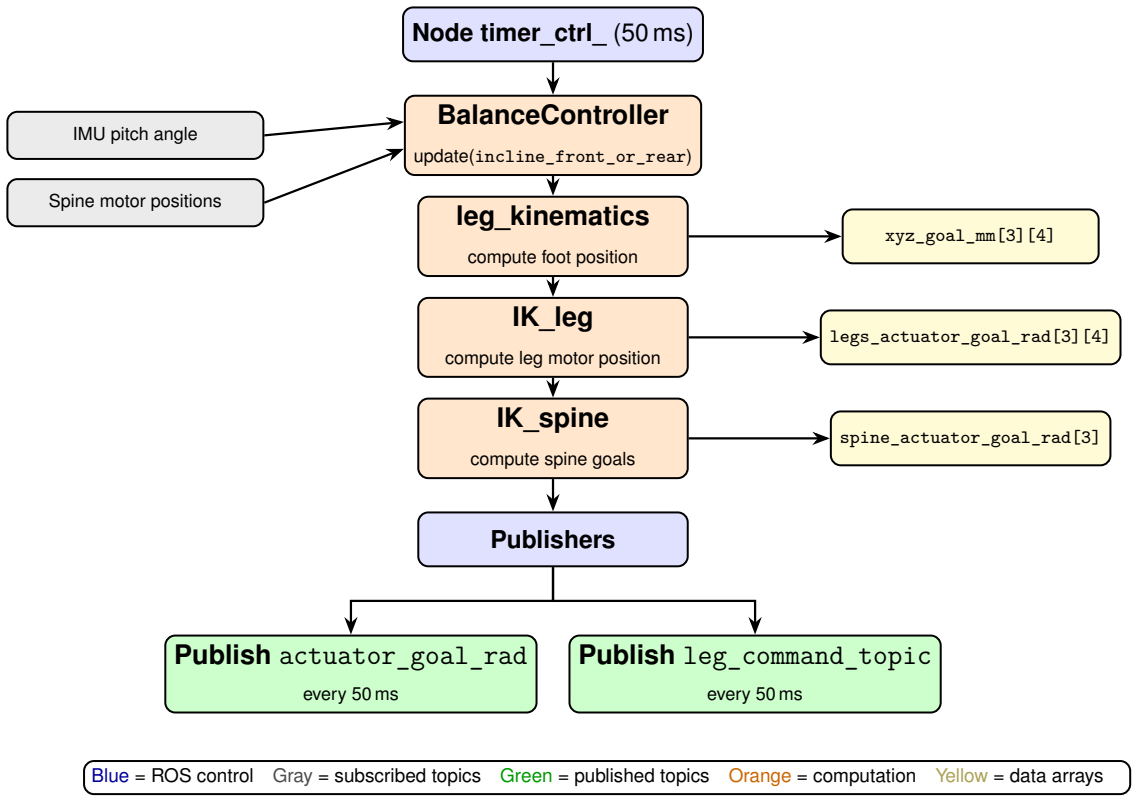
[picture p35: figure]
Node timer_ctrl_ (50 ms); BalanceController; update(incline_front_or_rear); leg_kinematics; compute foot position; IK_leg; compute leg motor position; IK_spine; compute spine goals; Publishers; IMU pitch angle; Spine motor positions; xyz_goal_mm[3][4]; legs_actuator_goal_rad[3][4]; spine_actuator_goal_rad[3]; Publish actuator_goal_rad; every 50 ms; Publish leg_command_topic

Blue = ROS control Gray = subscribed topics Green = published topics Orange = computation Yellow = data arrays

1) Kinematics
Exactly the same data layout as in the trot node is used:
xyz_goal_mm[3][4], | legs_actuator_goal_rad[3][4], | spine_actuator_goal_rad[3].

The leg_kinematics class calculates new foot position for either the front or the rear, depending on incline_front_or_rear, to keep the foot fixed on the inclined plane. Then,
the IK_leg class computes the joints’ positions for the affected pair of legs, and sets the
other pair to zero. Finally, the IK_spine class maps the requested body pitch into the two rear spine actuators (front spine stays at zero). Also, a FK_spine routine is available, as it was previously used to get the current pitch angle of the spine from the current spine motor position.
2) Control
BalanceController::update() runs every 50 ms. With incline_front_or_rear=1 (default), it keeps the rear horizontal by using the IMU pitch as the spine pitch request; the rear legs follow the inclined plane while the front legs stay at zero. With incline_front_or_rear=0, the front is kept horizontal: the node first estimates the pose via FK_spine, then slowly integrates the IMU pitch (kp-like term) to shape the target and updates foot/leg IK accordingly (cf Chapter 4, Section 4 on control techniques used for balance)

4 Software Design

3) Subscribers and publishers
Subscribers
- /euler_only or imu_data: IMU pitch used for balancing.
- joint_pos_topic: spine motor positions, needed for FK_spine.

Publishers
- actuator_goal_rad (Float64MultiArray, every 50 ms): one single line, with the 12 leg goals followed by the 3 spine goals.
- leg_command_topic (String, every 50 ms): MIT commands for all 15 actuators.

Note. In the control timer, the node first requests the three spine positions, updates the controller, prints the full goal vector for logging, and then publishes to both topics.

### 4.4 MuJoCo Simulation

The MuJoCo simulation was configured using a URDF file exported from the Fusion 360 model of the quadruped. Since ball joints are not supported in the URDF export, all ball joints in the Fusion model had to be replaced with hinge joints prior to export. After generating the URDF, these hinge joints were manually converted back to ball joints. However, MuJoCo does not support multiple ball joints on a single body. To work around this limitation, the spine links were split into two separate bodies and reconnected using the weld constraint. This approach is not entirely rigid, as the weld behaves more like a 1D spring-damper system attempting to hold the parts together, rather than enforcing a perfectly fixed connection. Nevertheless, this level of accuracy is sufficient for the simulation, whose primary purpose is to verify that the control commands do not risk damaging the physical prototype. An alternative approach that was also tested was to remove the spine links entirely and instead drive the motion using only a universal joint. This method worked particularly well as this solution eliminates the issue of the spine link not being perfectly rigid.

Figure 4-6: Rendering of the quadruped with the 19 hinge joints for URDF export

4 Software Design

The simulation was integrated into ROS 2 as a node that subscribes to the topic actuator_-goal_rad. This topic publishes a 15 ⇥ 1 array containing the desired actuator positions in radians for all joints. The ordering of the array is as follows:

[FR waist, FR hip, FR knee, FL waist, FL hip, FL knee, RR waist, RR hip, RR knee, RL waist, RL hip, RL knee, Front spine, RR spine, RL spine]

### 4.4.1 Control

The MuJoCo environment’s integrated control system was used for this simulation. Its parameters can be adjusted in the following section of the code (line 25):
1 | // Controller - related variables
2 | float_t ctrl_update_freq = 100;
3 | mjtNum last_update = 0;
4 | mjtNum ctrl;
| If proportional-derivative (PD) control is preferred, the actuators in the XML file must be
| changed from position to motor.
| 4.4.2 XML Models
| Two XML models are available:
| • model.xml Includes the full spine model and the weld constraint.
| • quadruped_UJ_activated.xml Uses only a universal joint for the spine, which directly
| drives the motion.
| Switching between the two is straightforward: modify the first line after the includes (line 23)
| to select the desired file:
1 | char filename[] = " quadruped_UJ_activated .xml ";
| 4.4.3 Sensor IDs
| To simplify model switching and improve code readability, sensor IDs are managed through
| dedicated .cpp and .hpp files. This allows sensors to be referenced by name rather than by
| index. For example:
1 | cur_actuator_pos [1][1] = d->sensordata[m->sensor_adr\[id_FL_femur_s_pos
| ]];
| Note that, due to the initial implementation, the waisthipknee joints are internally referred to
| as hipfemurtibia.
| Adding new sensors is straightforward:
1. Declare them in sensor_ids.hpp (as extern int).
2. Define them in sensor_ids.cpp and add them to the init_sensor_ids() function.

4 Software Design

### 4.4.4 Inclined Plane

A dedicated class was implemented to simulate an inclined plane. The parameters can be modified at the beginning of the code (line 30):
1 | // Inclined plane parameters
2 | float T_incline = 5; // Time to reach max_degree
3 | float max_degree = 0; // Starts at 0, reaches max_degree in T_incline
| seconds

## 5 Testing and Results

### 5.1 Testing Procedure and Recommendations

This section describes the testing procedure for the quadruped robot and provides practical recommendations based on the work carried out.

### 5.1.1 MIT Position Limits

To ensure safety in all commands requested by the user or the code, a safety check for the MIT command limits is implemented in prepare_payload_mit(). These values can be modified within the function:
1 | float q_limit_min = -M_PI;
2 | float q_limit_max = M_PI;

3
4 | if (can_bus == 5) {
5 | q_limit_min = -40 * DEG2RAD;
6 | q_limit_max = 40 * DEG2RAD;
7 | } else {
8 | if | (can_id ==1) {q_limit_min = -30 * DEG2RAD; q_limit_max = 30
| | * DEG2RAD; }
9 | else if (can_id ==2) {q_limit_min = -60 * DEG2RAD; q_limit_max = 60
| | * DEG2RAD; }
10 | else if (can_id==3) {q_limit_min = -135 * DEG2RAD; q_limit_max = 135
| | * DEG2RAD; }
11 | }

If the values exceed the hardware limits, the command is ignored and an error is logged in
| the terminal.

### 5.1.2 Communication Setup

It is essential to connect devices in the following order to ensure correct /dev/ttyACM
| assignments:
1. Front STM32 becomes ttyACM0
2. Rear STM32 becomes ttyACM1
3. IMU automatically detected

### 5.1.3 Useful Commands

Before running any ROS 2 nodes, ensure you are in the workspace and source the environ-
| ment:
1 | source install/setup.bash

I listed some commonly used commands:
| • Start IMU:

5 Testing and Results

1 ros2 launch yesense_std_ros2 yesense_node.launch.py

- Run the leg command node:
1 ros2 run leg_command leg_command_node
- List connected USB devices:
1 ls -l /dev/ttyACM*
- Send a leg command:
1 | ros2 topic pub -1 /leg_command_topic std_msgs/msg/String \
2 | " data : ’2,2,mit ,4.0,0.4,0,0,0’"
Replace mit with enable, disable, request, or set_zero_position as needed.
- List all ROS topics:
1 ros2 topic list
- Print euler_only topic data:
1 ros2 topic echo /euler_only

### 5.1.4 Final Recommendations

Before testing new motors or scripts:
- Always check motor position, speed and torque limits with the app provided by Damiao,
| as the position, velocity or torque value sent with MIT is not an absolute value but a
| percentage of the maximum value (cf Chapter 3, Section 3 Electronics Hardware)
- Verify Kp and Kv limits (same reason)
- Ensure these values match those used in the MIT commands.
- Keep all motors updated with the latest firmware, or at least ensure they are running the
| same firmware version.

### 5.2 Results

### 5.2.1 Hardware Analysis

Electronics Integration
The chosen hybrid architecture, combining a Raspberry Pi 5 with STM32 microcontrollers, proved highly effective during testing. The modular design allowed the Raspberry Pi to act purely as a high-level controller, while the STM32 boards handled the low-level CAN communication in real time. This not only improved reliability but also provided flexibility: the Raspberry Pi can be easily removed or replaced within minutes, and the system remains compatible with more powerful computers if required in the future. Overall, this configuration demonstrated robustness, portability, and straightforward maintainability.

5 Testing and Results

Mass Distribution
In addition to performance, the mass distribution of the quadruped was analyzed to identify how different subsystems contribute to the total weight. Table 5-1 presents a breakdown of the primary components and their respective contributions, expressed both in absolute mass and as a percentage of the total robot weight. In particular, the actuators represent the dominant fraction of the total mass (52%), which is typical for quadrupeds of this scale.

5 Testing and Results

Table 5-1: | Mass distribution of quadruped components.
Subsystem / Part | Material | Units Mass / unit [kg] Total [kg]
Actuators
DM6006 | – | 9 | 0.35 | 3.15
DM4010 | – | 6 | 0.30 | 1.80
Subtotal Actuators | | | | 4.95
Spine
Front actuator support Tough PLA | 1 | 0.055 | 0.055
Rear actuator support Tough PLA | 2 | 0.055 | 0.110
Spine support | Tough PLA | 1 | 0.165 | 0.165
Link (w/ ball joints) | Steel | 2 | 0.050 | 0.100
Bar | CFRP | 2 | 0.012 | 0.024
Universal joint | Steel | 1 | 0.220 | 0.220
Subtotal Spine | | | | 0.674
Rear body structure
Rear frame | CFRP | 1 | 0.365 | 0.365
Cover plates | Tough PLA | 4 | 0.096 | 0.384
Structural supports | Tough PLA | 1 | 0.172 | 0.172
Column | Aluminium | 2 | 0.005 | 0.010
Electronics support | Tough PLA | 1 | 0.004 | 0.004
Subtotal Rear body | | | | 0.935
Front body structure
Front frame | CFRP | 1 | 0.401 | 0.401
Cover plates | Tough PLA | 1 | 0.469 | 0.469
Supports | Tough PLA | 1 | 0.149 | 0.149
Column | Aluminium | 4 | 0.005 | 0.020
Electronics support | Tough PLA | 1 | 0.028 | 0.028
Subtotal Front body | | | | 1.039
Electronics
Raspberry Pi 5 | – | 1 | 0.064 | 0.064
STM32 Board | – | 2 | 0.025 | 0.050
Robomaster PDU | – | 2 | 0.025 | 0.050
Battery | – | 1 | 0.650 | 0.650
Wires | – | – | – | 0.05
Subtotal Electronics | | | | 0.864
| Leg
Frame | CFRP | 1 | 0.100 | 0.100
Waist to hip support | Tough PLA | 1 | 0.073 | 0.073
Hip to knee support | Tough PLA | 1 | 0.050 | 0.050
Foot structure | Tough PLA | 1 | 0.025 | 0.025
Gears for toothed belt Tough PLA | 1 | 0.031 | 0.031
Subtotal Leg | | | | 0.279
Total Robot Mass | | | | 9.5

5 Testing and Results

Figure 5-1 complements the table with a pie chart representation, where the dominant contribution of the actuators becomes evident. Such an analysis is useful not only to identify optimization opportunities (e.g., reducing actuator weight or redesigning the frame to shift the distribution), but also to benchmark the robot against other quadrupeds in terms of actuator-to-weight ratio.

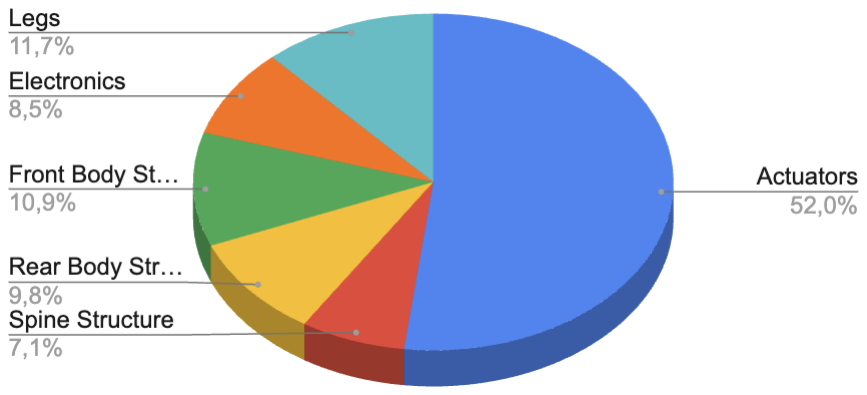
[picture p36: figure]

Figure 5-1: Mass distribution of the quadruped.

### 5.2.2 Test cases choice

The main objective of this thesis was to develop a research platform for investigating active spine designs. Accordingly, the test cases were selected based on the following criteria:
- Leg strength: the ability to sustain the quadrupeds weight while still enabling locomotion.
- Spine strength: the ability to emulate a rigid chassis during trotting and to balance the quadruped with sufficient speed and stability.

One of the test cases had to demonstrate that the quadruped is capable of walking. However, many distinct gaits are defined in the literature:
- Walk: the least tiring gait, consisting of a four-beat sequence in which each limb executes the cycle of liftswingsupportthrust in turn. At least two or three legs are always in contact with the ground, making it very stable.
- Amble: a two-beat gait where the forelimb and hindlimb on the same side move together. It is smoother than the walk and is often used as an intermediate-speed gait in animals such as horses.
- Trot: a two-beat diagonal gait in which the forelimb and hindlimb on opposite sides move together. It is symmetrical, relatively energy-efficient, and provides good stability at moderate speeds. This is also the most common gait used in quadruped robotics.
- Pace: a two-beat lateral gait in which the forelimb and hindlimb on the same side move together. Compared to the trot, it is less stable laterally but allows faster oscillations.
- Canter: a three-beat gait that is asymmetric; the sequence involves one hindlimb, followed by the opposite hindlimb and diagonal forelimb together, and finally the remaining forelimb. It provides smoother acceleration and is often used before transitioning to gallop.

5 Testing and Results

- Transverse gallop: a four-beat gait where the sequence starts from a hindlimb, then the opposite hindlimb, followed by the opposite forelimb, and finally the leading forelimb. It is the typical gallop seen in horses and allows high speed but with higher energy cost.
- Rotatory gallop: also a four-beat gait but with a different sequence, where the hindlimbs move one after the other and then the forelimbs. This gait is used by carnivores such as cheetahs and greyhounds, allowing very high speeds with the help of spinal flexion and extension.

After thorough consideration, the chosen gait for this project was the trot, as it is widely adopted in quadruped robotics for its balance of speed, energy efficiency, and stability. During gait execution, the spine must be sufficiently rigid to ensure that the body behaves as a stable chassis. This rigidity is essential in the current implementation, since it allows the gait dynamics to be analyzed without additional complexity from spinal motion. At the same time, maintaining the spine as a passive rigid structure provides a valuable baseline: in future work, it will be possible to compare this “rigid body” case directly with an active spine on the same quadruped platform. Such a comparison would be particularly relevant, as biological observations show that animals exploit spinal flexion and extension to increase stride length, energy efficiency, and speed. By first validating a rigid-body gait on this quadruped, subsequent experiments with an actuated spine could highlight the benefits in terms of locomotion performance, stability on uneven terrain, and agility during dynamic maneuvers such as jumps or sprints.

Another test was designed specifically for the spine, in order to demonstrate that it is also capable of controlling its degrees of freedom. A suitable and fast-to-implement experiment was to evaluate balance on an inclined surface, by controlling only the pitch angle of the spine. This test is sufficient to show that the actuated spine can provide corrective motion that contributes to whole-body stability. Naturally, more complex extensions are possible. For instance, the control could be extended to include not only the pitch but also the roll angle of the spine, requiring a coordinated strategy to combine both degrees of freedom. Nevertheless, restricting the experiment to pitch control was adequate for the purposes of this work, as it provided a clear and measurable demonstration of spinal actuation without introducing unnecessary complexity at this stage.

In the end, two primary tests were conducted to assess performance:
- Making the quadruped trot.
- Making the quadruped balance on an inclined plane.

All algorithms were first validated in simulation before being successfully implemented on the real robot. Since the trot relies on a hard-coded closed-loop trajectory, the achieved walking speed was approximately 4 cm/s. Figures 5-2 and 5-3 show the results obtained in simulation and on the physical platform, respectively.

5 Testing and Results


(a) Mujoco simulation | (b) Results on quadruped
Figure 5-2: | Simulation and results of trot test

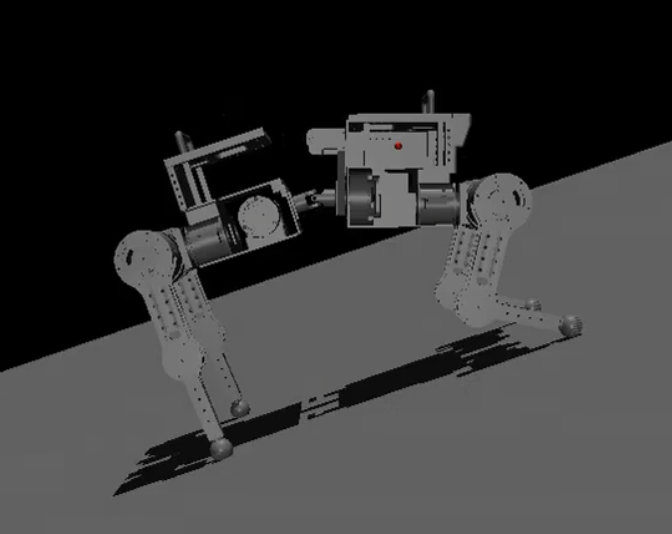
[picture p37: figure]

(a) Mujoco simulation | (b) Results on quadruped
Figure 5-3: | Simulation and results of balance on inclined surface test

## 6 Conclusion

The primary objective of this thesis was to design and develop a quasi-direct drive quadruped robot with an actuated spine, providing a robust research platform for future investigations. This goal was successfully achieved: the robot, named ASTRA, is fully controllable, capable of walking using a trot gait, and able to balance on an inclined surface. These demonstrations validate both the mechanical robustness of the design and the reliability of the embedded electronics and software architecture.

From a technical perspective, the work encompassed the complete development cycle of a robotic platform. The hardware design integrated lightweight CFRP structures with 3D-printed supports, optimized actuator placement, and a parallel spine mechanism capable of three degrees of freedom. The electronics architecture combined a Raspberry Pi 5 with STM32 microcontrollers, striking a balance between modularity, cost, and robustness. On the software side, ROS 2 nodes were implemented for gait generation, balance control, and hardware interfacing, with all algorithms first validated in a MuJoCo simulation before being deployed to the physical prototype. The results confirm that the chosen quasi-direct drive actuation scheme provides both transparency and sufficient torque, while the active spine expands the potential for more dynamic and adaptive locomotion.

Beyond the technical outcomes, this project was also a valuable personal milestone. As a mechanical engineer, it allowed me to extend my expertise into electronics and embedded software. The laboratory environment offered the opportunity to collaborate with PhD students and gain insight into ongoing research, giving me a clearer understanding of the challenges and directions in modern robotics. This experience reinforced my motivation to pursue robotics further and to contribute at the research level during my Masters studies.

Looking forward, several research directions remain open. The current control strategies were deliberately kept simple, with a hard-coded trot gait and basic spine pitch control. More advanced approaches such as Model Predictive Control, Central Pattern Generators, or reinforcement learning could leverage the full capabilities of the active spine. Additional studies on energy efficiency and dynamic maneuvers (e.g., jumps or sprints) would provide valuable insights into the role of spinal actuation in legged locomotion. Finally, the present mechanical design provides a solid foundation that can be further optimized if the quadruped is developed into a larger-scale research project in the future.

In conclusion, the thesis achieved its goal of building a reliable and versatile spinal quadruped, establishing a solid foundation for future research. ASTRA demonstrates that active spines are not only mechanically feasible but also open new avenues for studying agility, efficiency, and adaptability in quadruped robots.

## Literaturverzeichnis

[Rai-1986] M. H. Raibert, Legged Robots That Balance. Cambridge, MA: MIT Press, 1986.
[Lee-1996] K. F. Leeser, “Locomotion Experiments on a Planar Quadruped Robot with Articulated Spine”, M.S. thesis, Massachusetts Institute of Technology, 1996. [Rai-2008] M. Raibert, K. Blankespoor, G. Nelson, and R. Playter, “BigDog, the Rough-Terrain Quadruped Robot”, in Proceedings of the 17th World Congress of the International Federation of Automatic Control (IFAC), vol. 41, Elsevier, 2008, pp. 10 822–10 825. DOI: 10.3182/20080706-5-KR-1001.01833. (https://doi.org/10.3182/20080706-5-KR-1001.01833) [Sem-2011] C. Semini, N. G. Tsagarakis, E. Guglielmino, M. Focchi, F. Cannella, and
D. G. Caldwell, “Design of HyQ – a Hydraulically and Electrically Actuated Quadruped Robot”, Proceedings of the Institution of Mechanical Engineers, Part I: Journal of Systems and Control Engineering, vol. 225, no. 6, pp. 831– 849, 2011. DOI: 10.1177/0959651811402275. (https://doi.org/10.1177/0959651811402275)
[Hut-2016] M. Hutter, C. Gehring, D. Jud, et al., “ANYmal – a Highly Mobile and Dynamic Quadrupedal Robot”, in Proceedings of the 2016 IEEE/RSJ International Conference on Intelligent Robots and Systems (IROS), IEEE, 2016, pp. 38–44. DOI: 10.1109/IROS.2016.7758092. (https://doi.org/10.1109/IROS.2016.7758092)
[Bel-2017] D. C. Bellicoso, F. Jenelten, P. Fankhauser, C. Gehring, J. Hwangbo, and
M. Hutter, “Dynamic Locomotion and Whole-Body Control for Quadrupedal Robots”, in Proceedings of the 2017 IEEE/RSJ International Conference on Intelligent Robots and Systems (IROS), IEEE, 2017, pp. 3359–3365. DOI: 10.1109/IROS.2017.8206174. (https://doi.org/10.1109/IROS.2017.8206174)
[Ble-2018] G. Bledt, M. J. Powell, B. Katz, J. Di Carlo, P. M. Wensing, and S. Kim, “MIT Cheetah 3: Design and Control of a Robust, Dynamic Quadruped Robot”, in Proceedings of the 2018 IEEE/RSJ International Conference on Intelligent Robots and Systems (IROS), IEEE, 2018, pp. 2245–2252. DOI: 10 . 1109 /IROS.2018.8593885. (https://doi.org/10.1109/IROS.2018.8593885)
[DiC-2018] J. Di Carlo, P. M. Wensing, B. Katz, G. Bledt, and S. Kim, “Dynamic Locomotion in the MIT Cheetah 3 Through Convex Model-Predictive Control”, in Proceedings of the 2018 IEEE/RSJ International Conference on Intelligent Robots and Systems (IROS), IEEE, 2018, pp. 1–9. DOI: 10.1109/IROS.2018.8594448. (https://doi.org/10.1109/IROS.2018.8594448) [Kat-2019] B. Katz, J. Di Carlo, and S. Kim, “Mini Cheetah: A Platform for Pushing the Limits of Dynamic Quadruped Control”, in Proceedings of the 2019 IEEE International Conference on Robotics and Automation (ICRA), IEEE, 2019, pp. 6295–6301. DOI: 10.1109/ICRA.2019.8793865. (https://doi.org/10.1109/ICRA.2019.8793865)

Literaturverzeichnis

[Kau-2019] N. Kau, A. Schultz, N. Ferrante, and P. Slade, “Stanford Doggo: An Open-Source, Quasi-Direct-Drive Quadruped”, in Proceedings of the 2019 IEEE International Conference on Robotics and Automation (ICRA), IEEE, 2019, pp. 6309–6315. DOI: 10.1109/ICRA.2019.8794436. (https://doi.org/10.1109/ICRA.2019.8794436)
[Hwa-2019] J. Hwangbo, J. Lee, A. Dosovitskiy, et al., “Learning Agile and Dynamic Motor Skills for Legged Robots”, Science Robotics, vol. 4, no. 26, eaau5872, 2019. DOI: 10.1126/scirobotics.aau5872. (https://doi.org/10.1126/scirobotics.aau5872)
[Kho-2013] M. Khoramshahi, A. Spröwitz, A. Tuleu, M. N. Ahmadabadi, and A. J. Ijspeert, “Benefits of an Active Spine Supported Bounding Locomotion with a Small Compliant Quadruped Robot”, in Proceedings of the 2013 IEEE International Conference on Robotics and Automation (ICRA), IEEE, 2013, pp. 3329–3334. DOI: 10.1109/ICRA.2013.6631041. (https://doi.org/10.1109/ICRA.2013.6631041)
[Dup-2017] J. Duperret, B. Kramer, and D. E. Koditschek, “Core Actuation Promotes Self-Manipulability on a Direct-Drive Quadrupedal Robot”, in Proceedings of the 2016 International Symposium on Experimental Robotics (ISER), Springer, 2017, pp. 147–159.
[Pus-2013] J. L. Pusey, J. M. Duperret, G. C. Haynes, R. Knopf, and D. E. Koditschek, “Free-Standing Leaping Experiments with a Power-Autonomous, Elastic-Spined Quadruped”, in Proceedings of SPIE Defense, Security, and Sensing: Unmanned Systems Technology XV, vol. 8741, SPIE, 2013, 87410W. DOI: 10.1117/12.2016073. (https://doi.org/10.1117/12.2016073)
[Ye-2021] K. Ye and K. Karydis, “Modeling and Trajectory Optimization for Standing Long Jumping of a Quadruped with a Preloaded Elastic Prismatic Spine”, in Proceedings of the 2021 IEEE/RSJ International Conference on Intelligent Robots and Systems (IROS), IEEE, 2021, pp. 9208–9214. DOI: 10 . 1109 /IROS51168.2021.9636606. (https://doi.org/10.1109/IROS51168.2021.9636606)
[Cap-2023] J. D. Caporale, Z. Feng, S. Rozen-Levy, A. M. Carter, and D. E. Koditschek, “Twisting Spine or Rigid Torso: Exploring Quadrupedal Morphology via Trajectory Optimization”, in Proceedings of the 2023 IEEE International Conference on Robotics and Automation (ICRA), London, UK: IEEE, 2023, pp. 1177–1184. DOI: 10.1109/ICRA48891.2023.10160450. (https://doi.org/10.1109/ICRA48891.2023.10160450)
[Bha-2019] S. Bhattacharya, A. Singla, Abhimanyu, et al., “Learning Active Spine Behaviors for Dynamic and Efficient Locomotion in Quadruped Robots”, in Proceedings of the 2019 28th IEEE International Conference on Robot and Human Interactive Communication (RO-MAN), IEEE, 2019, pp. 1–8. DOI: 10.1109 /RO-MAN46459.2019.8956332. (https://doi.org/10.1109/RO-MAN46459.2019.8956332)

Literaturverzeichnis

[Li-2023] W. Li, Z. Zhou, and H. Cheng, “Dynamic Locomotion of a Quadruped Robot with Active Spine via Model Predictive Control”, in Proceedings of the 2023 IEEE International Conference on Robotics and Automation (ICRA), IEEE, 2023, pp. 1185–1191. DOI: 10.1109/ICRA48891.2023.10160896. (https://doi.org/10.1109/ICRA48891.2023.10160896) [Wan-2024] J. Wang, J. Cheng, J. Hu, W. Gao, and S. Zhang, “Spined Torso Renders Advanced Mobility for Quadrupedal Locomotion”, in Proceedings of the 2024 IEEE International Conference on Robotics and Automation (ICRA), Yoko-hama, Japan: IEEE, 2024, pp. 1457–1463. DOI: 10.1109/ICRA57147.2024 .10610113. (https://doi.org/10.1109/ICRA57147.2024.10610113)
[Ras-2023] Raspberry Pi 5 Product Brief, Accessed: 2025-09-01, Raspberry Pi Ltd, 2023. [ST-2023a] STM32H723/733 Microcontrollers Datasheet, Accessed: 2025-09-01, STMicroelectronics, 2023.
[ST-2021] AN5348: Getting Started with STM32H7 Series MCUs, Application Note, Accessed: 2025-09-01, STMicroelectronics, 2021.
[Zho-2023] C. Zhou and N. Tsagarakis, “On the Comprehensive Kinematics Analysis of a Humanoid Parallel Ankle Mechanism”, ASME Journal of Mechanisms and Robotics, 2023, Available as draft preprint.

## 7 List of Figures

Figure 1-1 From left to right: MIT Mini Cheetah (MIT), ANYmal (ETH Zurich), Spot

Figure 2-4 Overview of communications with usb ports, can buses and can ids . . . 12 Figure 2-5 Standard CAN-FD frame (when not specified bit = 1) from [ST-2021] . . 13

Figure 3-1 Origin of the frame on the leg in its initial position for IK and associated

7 List of Figures

Figure 3-3 Quadruped with end-effector desired position for front right (FR) leg . . . 30

Figure 3-5 Front-right leg view in leg plane with end effector desire position . . . . 31

Figure 4-3 Function call sequence for position control in mujoco_node.cpp ..... 45

Figure 4-6 Rendering of the quadruped with the 19 hinge joints for URDF export . . 52

## 8 List of Tables

Table 1-1 Specifications of selected quadrupeds compared to the developed prototype. 2

## A Anhang
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

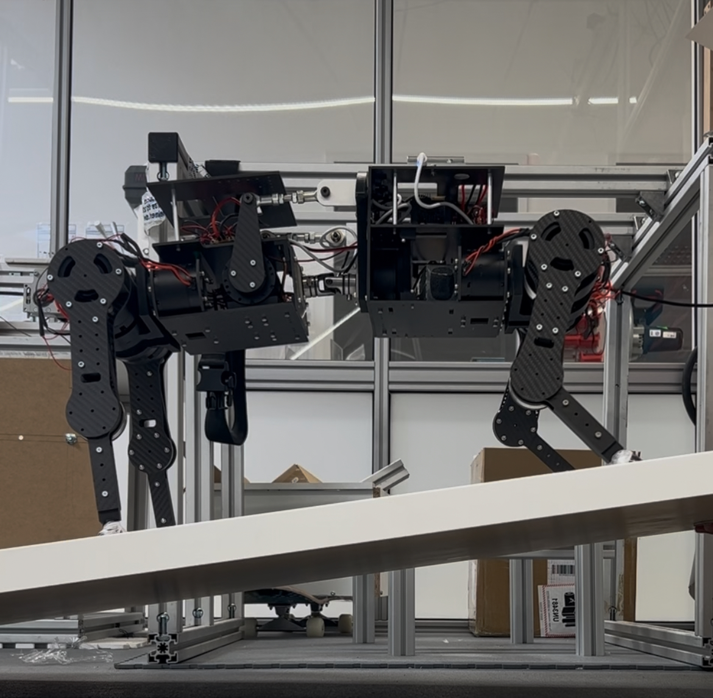
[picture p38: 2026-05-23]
docs/images/balance_inclined.jpg

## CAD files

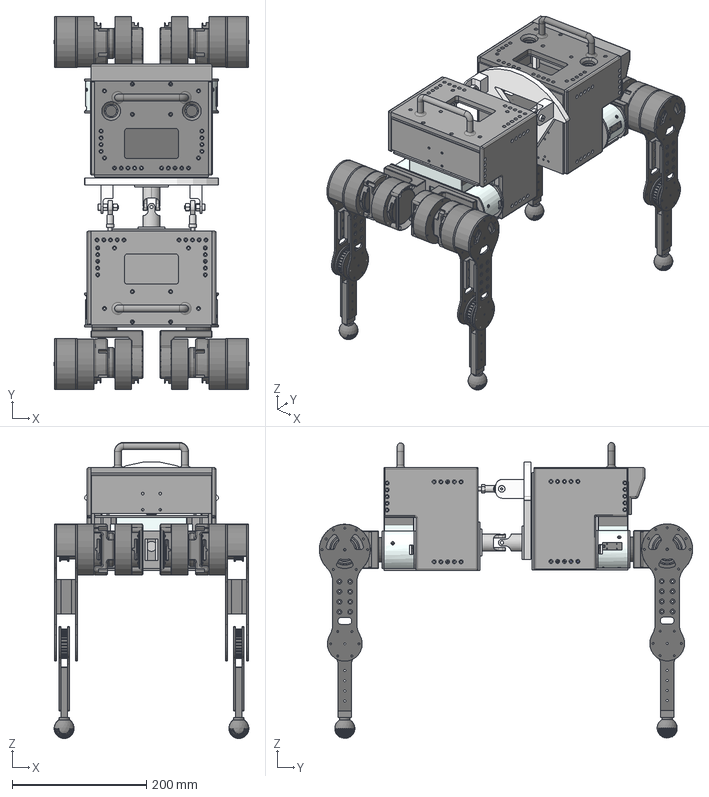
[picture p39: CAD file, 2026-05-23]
cad/ASTRA_quadruped.step
290.0 x 555.7 x 440.5 mm
SPINE_BASE
FR_tibia
FR_femur
FR_hip
FL_tibia
FL_femur
FL_hip
RR_tibia
RR_femur
RR_hip
RL_tibia
RL_femur
RL_hip
frontbase
backbase
spine_R_link
spine_R_bar
spine_RL_link
spine_L_bar

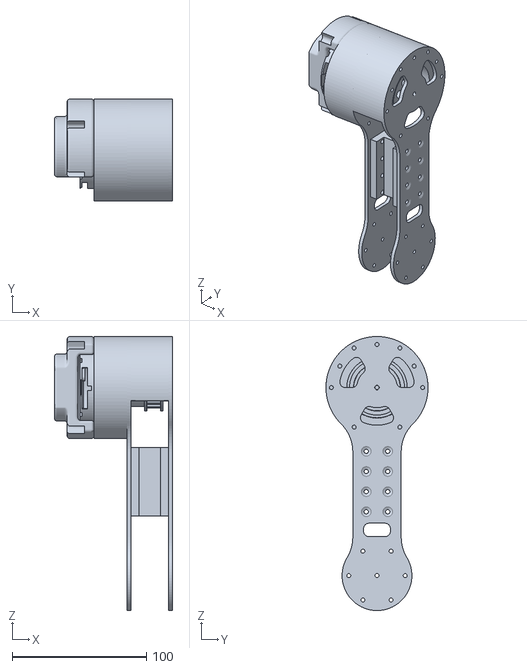
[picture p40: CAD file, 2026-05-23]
ros2_ws/src/mujoco_interface/model/meshes/RR_femur.stl
88.0 x 76.0 x 204.0

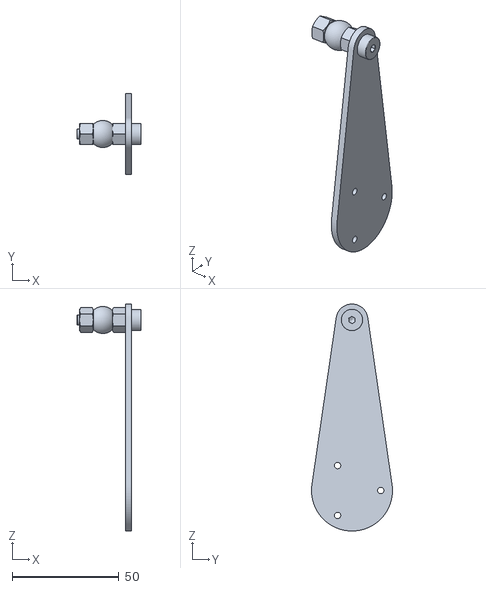
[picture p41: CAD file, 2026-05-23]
ros2_ws/src/mujoco_interface/model/meshes/spine_R_bar.stl
30.2 x 38.0 x 106.5

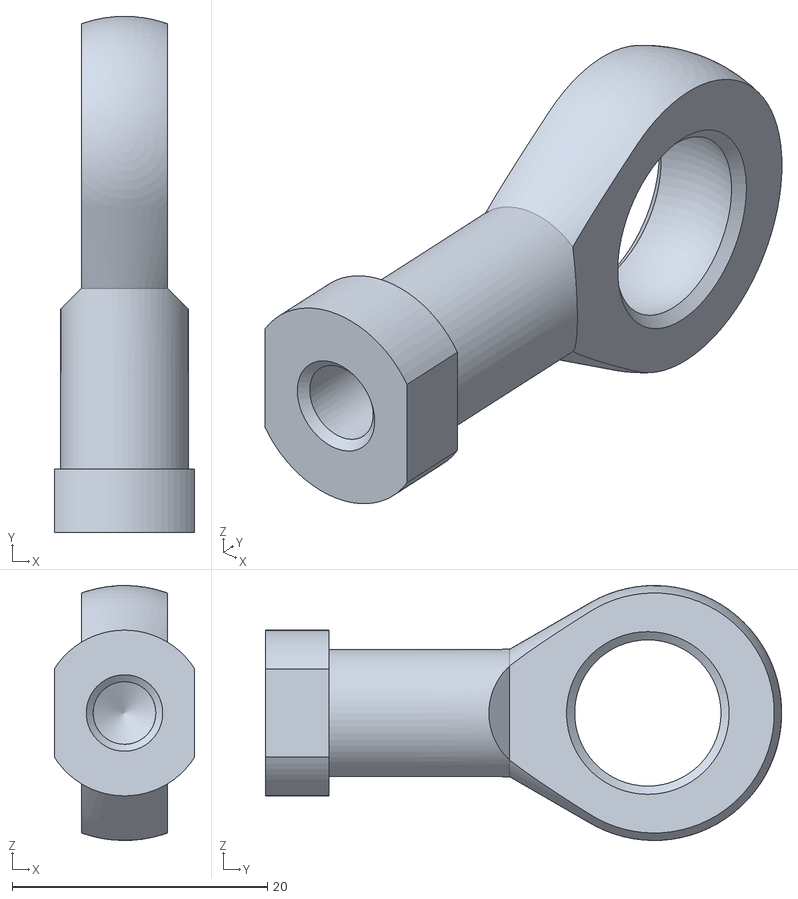
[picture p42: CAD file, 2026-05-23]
ros2_ws/src/mujoco_interface/model/meshes/spine_FR_link.stl
11.0 x 40.5 x 20.0

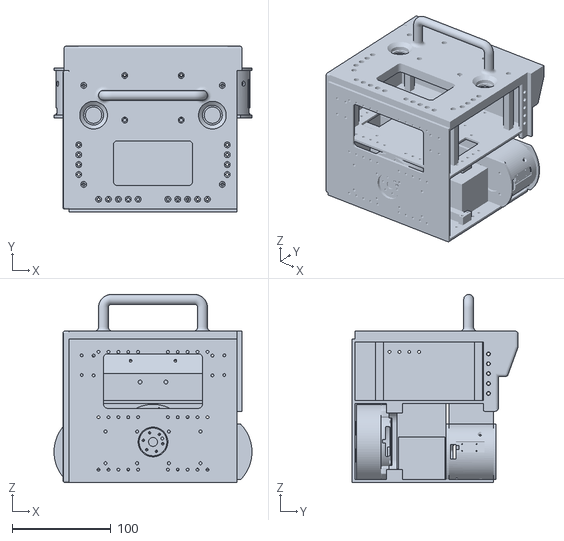
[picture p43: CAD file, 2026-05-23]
ros2_ws/src/mujoco_interface/model/meshes/frontbase.stl
200.0 x 168.0 x 190.0

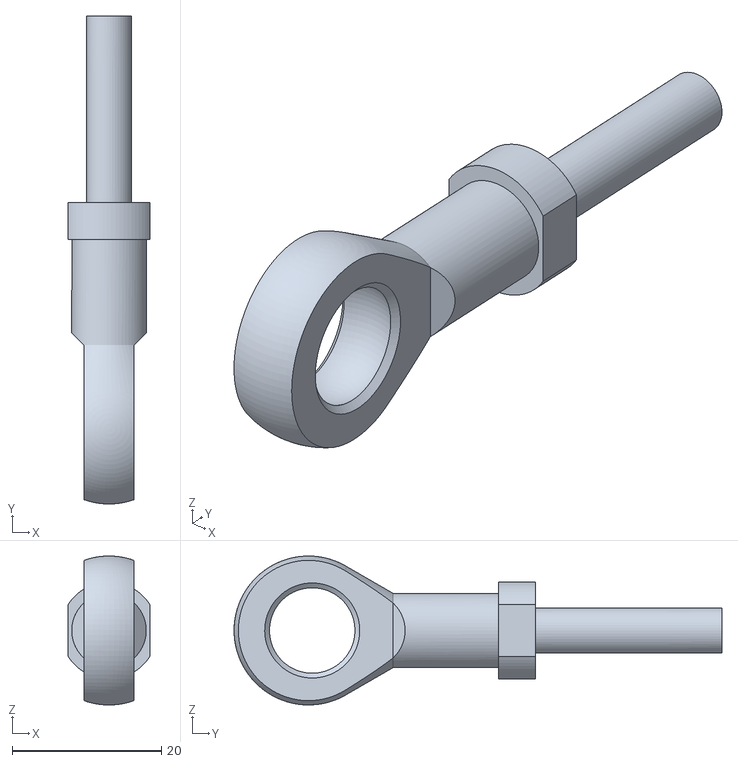
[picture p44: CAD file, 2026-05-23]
ros2_ws/src/mujoco_interface/model/meshes/spine_RL_link.stl
11.0 x 65.5 x 20.0

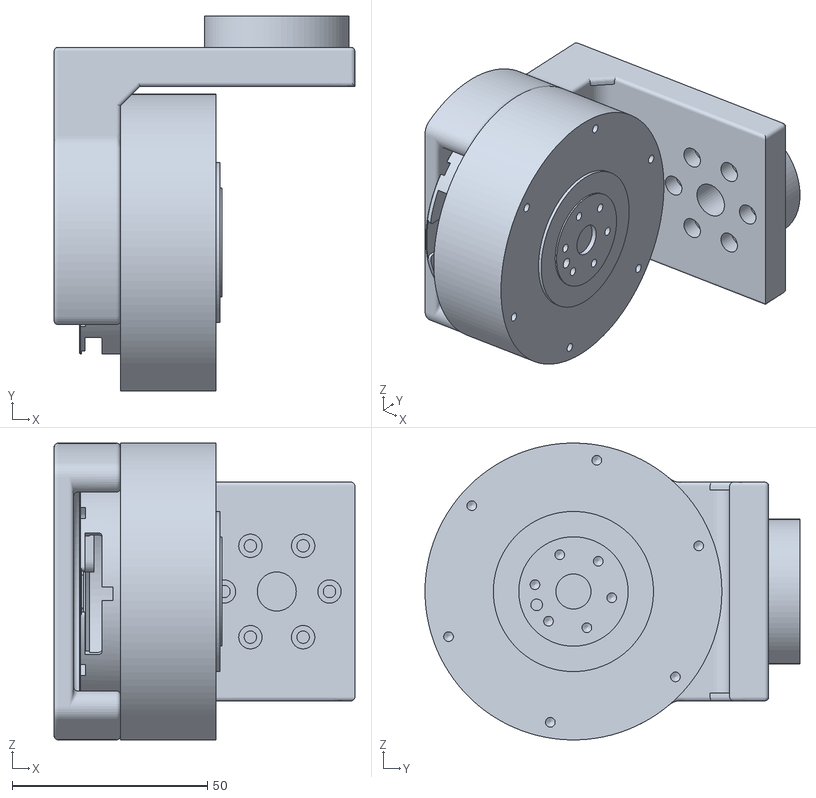
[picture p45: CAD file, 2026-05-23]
ros2_ws/src/mujoco_interface/model/meshes/RR_hip.stl
77.0 x 96.0 x 76.0

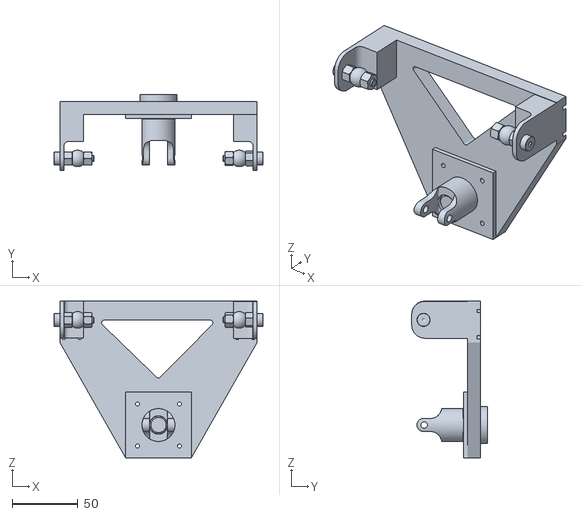
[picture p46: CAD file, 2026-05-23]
ros2_ws/src/mujoco_interface/model/meshes/SPINE_BASE.stl
159.0 x 57.5 x 119.2

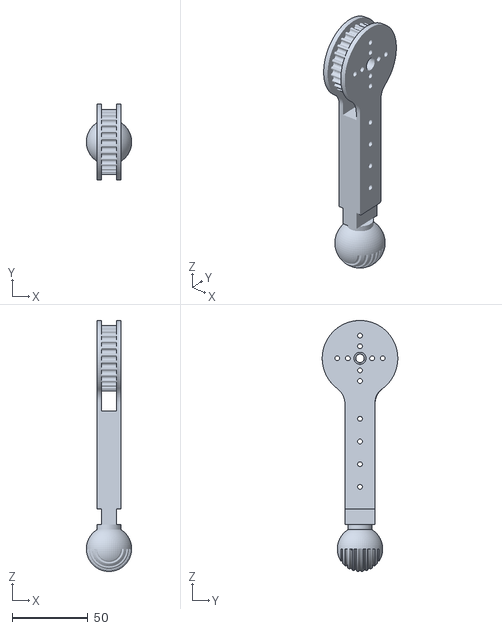
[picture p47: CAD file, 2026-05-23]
ros2_ws/src/mujoco_interface/model/meshes/RR_tibia.stl
30.0 x 50.0 x 165.9

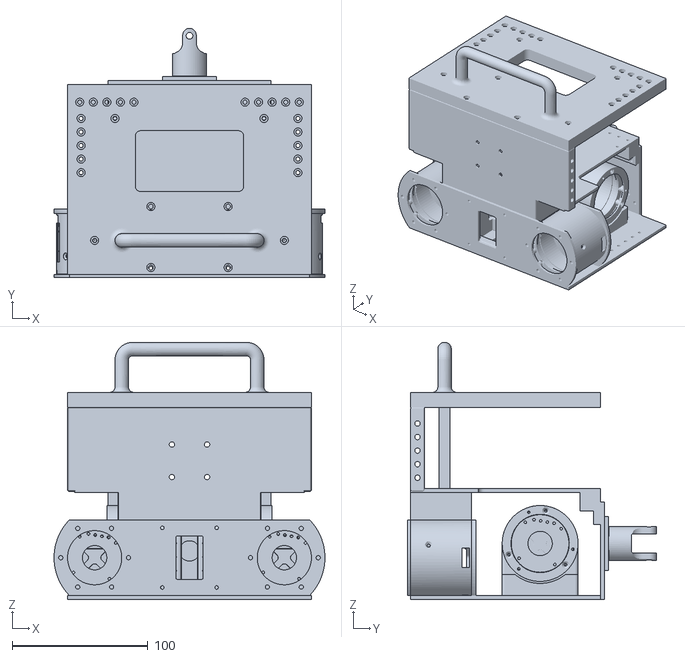
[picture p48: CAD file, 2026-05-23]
ros2_ws/src/mujoco_interface/model/meshes/backbase.stl
200.0 x 184.0 x 190.0

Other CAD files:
ros2_ws/src/mujoco_interface/model/meshes/RL_femur.stl
ros2_ws/src/mujoco_interface/model/meshes/spine_RR_link.stl
ros2_ws/src/mujoco_interface/model/meshes/FL_hip.stl
ros2_ws/src/mujoco_interface/model/meshes/spine_L_bar.stl
ros2_ws/src/mujoco_interface/model/meshes/RL_hip.stl
ros2_ws/src/mujoco_interface/model/meshes/FL_tibia.stl
ros2_ws/src/mujoco_interface/model/meshes/RL_tibia.stl
ros2_ws/src/mujoco_interface/model/meshes/FR_tibia.stl
ros2_ws/src/mujoco_interface/model/meshes/FL_femur.stl
ros2_ws/src/mujoco_interface/model/meshes/FR_femur.stl
ros2_ws/src/mujoco_interface/model/meshes/FR_hip.stl
ros2_ws/src/mujoco_interface/model/meshes/spine_FL_link.stl

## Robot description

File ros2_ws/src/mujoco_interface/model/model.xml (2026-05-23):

<mujoco model="quadruped">
    <compiler angle="radian" eulerseq="XYZ" />
    <option gravity="0 0 0" timestep="0.001"/> 
    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
      <worldbody>
        <light directional="true" pos="-0.5 0.5 3" dir="0 0 -1" />
        <body name="ground" pos="0 0 0">
            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
        </body>
        <body name="frontbase" pos="0.0 0.0 0.05" euler="0.0 0.0 0.0">
        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
            <joint name="root" type="free" />
            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
            <inertial mass="2.7047567302273086" pos="0.00033440222387868623 0.1245660632194667 0.2884083159461461" fullinertia="0.01078220929242324 0.013457553343312278 0.013262848443079664 1.1086881562630236e-05 2.426939650604682e-05 -0.0005029335341283497" />
            <body name="SPINE_BASE" pos="0.0 0.0 0.0" euler="0.0 -0.0 0.0">
                <joint name="F_j_spine" type="hinge" axis="0.0 -1.0 0.0" pos="0.0 0.048 0.2765" damping="0.0"/>
                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
                <inertial mass="0.31335795014290313" pos="3.392857252372269e-05 0.02698902626004699 0.30937648052390193" fullinertia="0.0004972224121499481 0.00096065696826848 0.0005518668776431874 -1.7053173613796147e-07 5.967022642829059e-08 1.8881962424268858e-05" />
                <body name="backbase" pos="0.0 0.0 0.0" euler="0.0 -0.0 0.0">
                    <joint name="j_universal" type="ball" pos="0.0 0.0 0.2765" damping="0.0"/>
                    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
                    <inertial mass="2.3349797051174357" pos="0.00013038137961569882 -0.10877171233725845 0.289194925915773" fullinertia="0.009087224494453011 0.011894123164930326 0.012186912807923042 2.1845326624663316e-06 4.249097312183789e-06 -6.126653941354587e-06" />
                    <body name="spine_L_bar" pos="0.0 0.0 0.0" euler="0.0 -0.0 0.0">
                        <joint name="RL_j_spine" type="hinge" axis="-1.0 0.0 0.0" pos="-0.061 -0.0805 0.2765" damping="0.0"/>
                        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
                        <inertial mass="0.03164580194616816" pos="-0.06755810312118324 -0.08039586581758262 0.33670530069433136" fullinertia="3.095324773523707e-05 3.1815550520951016e-05 2.89296070835705e-06 -2.062111216410479e-08 -3.7219913899651713e-06 -6.522642423108325e-08" />
                        <body name="spine_RL_link" pos="0.0 0.0 0.0" euler="0.0 -0.0 0.0">
                            <joint name="RL_j_link" type="ball" pos="-0.0615 -0.0805 0.3565" damping="0.0"/>
                            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
                            <inertial mass="0.02899974002495084" pos="-0.06149999999987106 -0.06295174717543707 0.35649999999854837" fullinertia="8.563419834303233e-06 6.156065880365616e-07 8.243247599980783e-06 1.1424780392566003e-17 6.353424730765056e-17 -9.497611030973019e-17" />
                        </body>
                    </body>
                    <body name="spine_R_bar" pos="0.0 0.0 0.0" euler="0.0 -0.0 0.0">
                        <joint name="RR_j_spine" type="hinge" axis="1.0 0.0 0.0" pos="0.061 -0.0805 0.2765" damping="0.0"/>
                        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
                        <inertial mass="0.031645801946168124" pos="0.06759945826011354 -0.08050000000314 0.3367056283650498" fullinertia="3.095234208204314e-05 3.181968096638418e-05 2.8953645025755212e-06 -1.279900664619138e-16 3.6961510613363726e-06 1.543253372315867e-15" />
                        <body name="spine_RR_link" pos="0.0 0.0 0.0" euler="0.0 -0.0 0.0">
                            <joint name="RR_j_link" type="ball" pos="0.0615 -0.0805 0.3565" damping="0.0"/>
                            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
                            <inertial mass="0.028999740024949126" pos="0.061499999999797876 -0.06295174717325776 0.3565000000126479" fullinertia="8.563419834318412e-06 6.156065880513067e-07 8.243247599981678e-06 3.5778671692021646e-17 6.10405823109339e-17 1.7141236346995825e-16" />
                        </body>
                    </body>
                    <body name="RR_hip" pos="0.0 0.0 0.0" euler="0.0 -0.0 0.0">
                        <joint name="RR_j_hip" type="hinge" axis="0.0 -1.0 0.0" pos="0.07 -0.176 0.266" damping="0.0" />
                        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
                        <inertial mass="0.42765614096569765" pos="0.04127800942400755 -0.2273092587519674 0.26606812124931534" fullinertia="0.0003819813177835876 0.00022425957082698733 0.0003062069227042566 -2.5639633945336374e-05 5.604986032681919e-07 2.0864847461235514e-07" />
                        <body name="RR_femur" pos="0.0 0.0 0.0" euler="0.0 -0.0 0.0">
                            <joint name="RR_j_femur" type="hinge" axis="1.0 0.0 0.0" pos="0.056 -0.234 0.266" damping="0.0"/>
                            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
                            <inertial mass="0.5478239660925199" pos="0.10262713634913981 -0.23333676163791178 0.2564743290521438" fullinertia="0.0009210868412945078 0.0009515235171001224 0.0003898366261748873 1.0369006426390326e-05 0.00012862808425460025 -3.44730242726049e-06" />
                            <body name="RR_tibia" pos="0.0 0.0 0.0" euler="0.0 -0.0 0.0">
                                <joint name="RR_j_tibia" type="hinge" axis="1.0 0.0 0.0" pos="0.113 -0.234 0.126" damping="0.0"/>
                                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
                                <inertial mass="0.06643041309117047" pos="0.1300000003100186 -0.23399974067058146 0.07451621272270392" fullinertia="0.0001728263651286045 0.00016950454321351953 7.324185496569019e-06 1.44164288016016e-09 8.782037597132586e-17 1.432228884318612e-09" />
                            </body>
                        </body>
                    </body>
                    <body name="RL_hip" pos="0.0 0.0 0.0" euler="0.0 -0.0 0.0">
                        <joint name="RL_j_hip" type="hinge" axis="0.0 -1.0 0.0" pos="-0.07 -0.176 0.266" damping="0.0" />
                        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
                        <inertial mass="0.42765614096569793" pos="-0.041278008804007546 -0.22730925875196725 0.26593187827114756" fullinertia="0.00038198131778947875 0.0002242595708328715 0.00030620692270427394 2.563963394533117e-05 5.60496829816147e-07 -2.0865824064408844e-07" />
                        <body name="RL_femur" pos="0.0 0.0 0.0" euler="0.0 -0.0 0.0">
                            <joint name="RL_j_femur" type="hinge" axis="-1.0 -0.0 -0.0" pos="-0.056 -0.234 0.266" damping="0.0"/>
                            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
                            <inertial mass="0.5478239660925199" pos="-0.10262713572913987 -0.23333676163791509 0.25636797041582277" fullinertia="0.0009199706233370408 0.0009504072991454657 0.00038983662617207704 -1.0369006426445837e-05 -0.00012716627840188635 -3.5134260216729274e-06" />
                            <body name="RL_tibia" pos="0.0 0.0 0.0" euler="0.0 -0.0 0.0">
                                <joint name="RL_j_tibia" type="hinge" axis="-1.0 0.0 0.0" pos="-0.113 -0.234 0.126" damping="0.0"/>
                                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
                                <inertial mass="0.06643041309117051" pos="-0.1299999996900186 -0.23400025932378982 0.07451621072657212" fullinertia="0.0001728263651286444 0.0001695045432135191 7.32418549660805e-06 1.4416428792927982e-09 -8.738669510233166e-17 -1.4322288387821208e-09" />
                            </body>
                        </body>
                    </body>
                </body>
                <body name="spine_FR_link" pos="0.0 0.0 0.0" euler="0.0 -0.0 0.0">
                    <joint name="FR_j_link" type="ball" pos="0.0615 -0.0005 0.3565" damping="0.0"/>
                    <joint name="FR_j_link_slide" type="slide" axis="0 1 0" pos="0.0615 -0.0045 0.3565" damping="1e3" stiffness="1e7" springref="0"/>
                    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
                    <inertial mass="0.022341134395664226" pos="0.06150000000021454 -0.011356679906857457 0.3565000000116856" fullinertia="3.6921940064428733e-06 5.856428636689774e-07 3.372021770187196e-06 3.628011519679619e-17 3.74049749507499e-17 3.7052609244692114e-17" />
                </body>
                <body name="spine_FL_link" pos="0.0 0.0 0.0" euler="0.0 -0.0 0.0">
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

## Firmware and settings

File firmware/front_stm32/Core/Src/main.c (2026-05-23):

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
/* Includes ------------------------------------------------------------------*/
#include "main.h"
#include "usb_device.h"

/* USER CODE BEGIN Includes */
#include <stdio.h>
#include <string.h>
#include "usbd_cdc_if.h"

extern USBD_HandleTypeDef hUsbDeviceHS;

/* USER CODE END Includes */


FDCAN_HandleTypeDef hfdcan1;
FDCAN_HandleTypeDef hfdcan2;

void SystemClock_Config(void);
static void MPU_Config(void);
static void MX_GPIO_Init(void);
static void MX_FDCAN1_Init(void);
static void MX_FDCAN2_Init(void);
/* USER CODE BEGIN 0 */
float live_position3 = 0.0f;
float live_position2 = 0.0f;
float live_position = 0.0f;

void HAL_FDCAN_RxFifo0Callback(FDCAN_HandleTypeDef *hfdcan, uint32_t RxFifo0ITs)
{
    if ((RxFifo0ITs & FDCAN_IT_RX_FIFO0_NEW_MESSAGE) != RESET)
    {
        FDCAN_RxHeaderTypeDef RxHeader;
        uint8_t rx_data[8];

        if (HAL_FDCAN_GetRxMessage(hfdcan, FDCAN_RX_FIFO0, &RxHeader, rx_data) != HAL_OK)
        {
            Error_Handler();
        }

        if (rx_data[2] == 0x33 && rx_data[3] == 80) {
            uint32_t raw = (rx_data[7] << 24) | (rx_data[6] << 16) |
                           (rx_data[5] << 8) | rx_data[4];
            float value;
            memcpy(&value, &raw, sizeof(float));

            // Round to 3 decimals (optional)
            value = ((int)(value * 1000)) / 1000.0f;

            // Send float to Pi over USB
            CDC_Transmit_HS((uint8_t*)&value, sizeof(float));
        }
    }
}

/* USER CODE END 0 */

/**
  * @brief  The application entry point.
  * @retval int
  */
int main(void)
{

  /* MPU Configuration--------------------------------------------------------*/
  MPU_Config();

  /* MCU Configuration--------------------------------------------------------*/

  /* Reset of all peripherals, Initializes the Flash interface and the Systick. */
  HAL_Init();

  /* Configure the system clock */
  SystemClock_Config();

  /* Initialize all configured peripherals */
  MX_GPIO_Init();
  MX_FDCAN1_Init();
  MX_FDCAN2_Init();
  MX_USB_DEVICE_Init();
  /* USER CODE BEGIN 2 */
  extern uint8_t CDC_Transmit_HS(uint8_t* Buf, uint16_t Len);
  CDC_Transmit_HS((uint8_t*)"STM32 USB READY\n", 17);

  HAL_FDCAN_Start(&hfdcan1);
  HAL_FDCAN_Start(&hfdcan2);
  HAL_FDCAN_ActivateNotification(&hfdcan1, FDCAN_IT_RX_FIFO0_NEW_MESSAGE, 0);
  HAL_FDCAN_ActivateNotification(&hfdcan2, FDCAN_IT_RX_FIFO0_NEW_MESSAGE, 0);

  /* USER CODE END 2 */

  /* Infinite loop */
  /* USER CODE BEGIN WHILE */
  while (1)
  {
    /* USER CODE END WHILE */

    /* USER CODE BEGIN 3 */
  }
  /* USER CODE END 3 */
}

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
 /* MPU Configuration */

void MPU_Config(void)
{
  MPU_Region_InitTypeDef MPU_InitStruct = {0};

  /* Disables the MPU */
  HAL_MPU_Disable();

  /** Initializes and configures the Region and the memory to be protected
  */
  MPU_InitStruct.Enable = MPU_REGION_ENABLE;
  MPU_InitStruct.Number = MPU_REGION_NUMBER0;
  MPU_InitStruct.BaseAddress = 0x0;
  MPU_InitStruct.Size = MPU_REGION_SIZE_4GB;
  MPU_InitStruct.SubRegionDisable = 0x87;
  MPU_InitStruct.TypeExtField = MPU_TEX_LEVEL0;
  MPU_InitStruct.AccessPermission = MPU_REGION_NO_ACCESS;
  MPU_InitStruct.DisableExec = MPU_INSTRUCTION_ACCESS_DISABLE;
  MPU_InitStruct.IsShareable = MPU_ACCESS_SHAREABLE;
  MPU_InitStruct.IsCacheable = MPU_ACCESS_NOT_CACHEABLE;
  MPU_InitStruct.IsBufferable = MPU_ACCESS_NOT_BUFFERABLE;

  HAL_MPU_ConfigRegion(&MPU_InitStruct);
  /* Enables the MPU */
  HAL_MPU_Enable(MPU_PRIVILEGED_DEFAULT);

}

/**
  * @brief  This function is executed in case of error occurrence.
  * @retval None
  */
void Error_Handler(void)
{
  /* USER CODE BEGIN Error_Handler_Debug */
  /* User can add his own implementation to report the HAL error return state */
  __disable_irq();
  while (1)
  {
  }
  /* USER CODE END Error_Handler_Debug */
}

#ifdef  USE_FULL_ASSERT
/**
  * @brief  Reports the name of the source file and the source line number
  *         where the assert_param error has occurred.
  * @param  file: pointer to the source file name
  * @param  line: assert_param error line source number
  * @retval None
  */
void assert_failed(uint8_t *file, uint32_t line)
{
  /* USER CODE BEGIN 6 */
  /* User can add his own implementation to report the file name and line number,
     ex: printf("Wrong parameters value: file %s on line %d\r\n", file, line) */
  /* USER CODE END 6 */
}
#endif /* USE_FULL_ASSERT */

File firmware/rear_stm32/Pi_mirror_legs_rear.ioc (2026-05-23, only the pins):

Mcu.UserName=STM32H723VGTx
PA11.Signal=USB_OTG_HS_DM
PA12.Signal=USB_OTG_HS_DP
PB5.Signal=FDCAN2_RX
PB6.Signal=FDCAN2_TX
PD0.Signal=FDCAN1_RX
PD1.Signal=FDCAN1_TX
PD12.Signal=FDCAN3_RX
PD13.Signal=FDCAN3_TX

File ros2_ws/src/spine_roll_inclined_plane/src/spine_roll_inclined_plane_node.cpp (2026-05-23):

#include <cstdio>
#include <array>
#include <rclcpp/rclcpp.hpp>
#include <yesense_interface/msg/euler_only.hpp>
#include <cmath>
#include <iostream>
#include <iomanip>
#include <algorithm>
#include <std_msgs/msg/float64_multi_array.hpp>
#include <std_msgs/msg/string.hpp>
#include "std_msgs/msg/float64.hpp"
#include <chrono>
#include <mutex>
using namespace std::chrono_literals;

constexpr float DEG2RAD = static_cast<float>(M_PI / 180.0);
int incline_front_or_rear = 1; // =0 keep front horizontal / =1 keep rear horizontal

// ---------------------------- CONVENTIONS ----------------------------
float angle_[3] ={0}; // is an array containing the angle value of in order: pitch, roll, and yaw, in my frame: x towards
float angle_vel[3]={0};
float inclined_angle = 0;
// ------------------------------------------------------------------------------------

// ----------------------------------- Parameters [m] -----------------------------------
const double X_goal_endeffector = 0.06;

const float r_A0[3][2] = {{0,0},        {0.065,-0.065}, {0.061,0.061}};     
const float r_B0[3][2] = {{0.08,0.08},  {0.065,-0.065}, {0.061,0.061}};
const float r_C0[3][2] = {{0.08,0.08},  {0.065,-0.065}, {0,0}};

float y_o_rear = 0.176;
float z_o_rear = - 0.011;
float y_o_front = 0.188;
float z_o_front = - 0.011;

float y_P_rear = 0.232;
float z_P_rear = - 0.292;
float y_P_front = 0.246;
float z_P_front = - 0.292;

float o_initial_pos_rear[2] = {y_o_rear , z_o_rear};
float yz_initial_pos_foot_rear[2] = {y_P_rear, z_P_rear};
float o_initial_pos_front[2] = {y_o_front , z_o_front};
float yz_initial_pos_foot_front[2] = {y_P_front, z_P_front};

// ----------------------------------- Variables -----------------------------------
float theta_act[3] = {0,0,0}; // quadruped's current rear spine actuator position --> [0] : F, [1] : RR, [2] : RL

// VALID FOR ALL: leg*3 + joint (order: FR, FL, RR, RL) && spine (order: F, RR, RL)
double xyz_goal_mm[3][4];
double legs_actuator_goal_rad[3][4] = {0};
double spine_actuator_goal_rad[3] = {0};

// ----------------------------------- Variables IK -----------------------------------
float r_C_IK[3][2] = {0};
float theta_act_IK[2] = {0};
float x_c_IK[2];                // [0] : my pitch, [1] : my yaw

// ----------------------------------- Variables FK -----------------------------------
float x_c_FK[2] = {0};  // [0] : my pitch, [1] : my yaw // equivalently [0] : his roll, [1] : his pitch
float r_B_FK[3][2] = {{0}};
float r_C_FK[3][2] = {{0}};

inline void cross3(const float a[3],const float b[3],float o[3]){
    o[0]=a[1]*b[2]-a[2]*b[1];
    o[1]=a[2]*b[0]-a[0]*b[2];
    o[2]=a[0]*b[1]-a[1]*b[0];
}
inline float dot3(const float a[3],const float b[3]){
    return a[0]*b[0]+a[1]*b[1]+a[2]*b[2];
}

// -----------------------------------   Code -----------------------------------
class leg_kinematics {
public:
    void compute_inclined_foot_pos(float pitch_imu, float yz_init_foot_pos[2], float o_initial_pos[2]){
        float s = std::sin(pitch_imu),  c = std::cos(pitch_imu);
        yz_inclined_pos_foot[0] = (yz_init_foot_pos[0] * c - yz_init_foot_pos[1] * s - o_initial_pos[0]);
        yz_inclined_pos_foot[1] = (yz_init_foot_pos[0] * s + yz_init_foot_pos[1] * c - o_initial_pos[1]);

        if (incline_front_or_rear == 1){
            for (int i = 2; i < 4; i++)
            {
                xyz_goal_mm[0][i] = ((i ==2) ? -X_goal_endeffector : X_goal_endeffector);
                xyz_goal_mm[1][i] = yz_inclined_pos_foot[0];
                xyz_goal_mm[2][i] = yz_inclined_pos_foot[1];
            }
        }
        else if (incline_front_or_rear == 0){
            for (int i = 0; i < 2; i++)
            {
                xyz_goal_mm[0][i] = ((i ==1) ? -X_goal_endeffector : X_goal_endeffector);
                xyz_goal_mm[1][i] = yz_inclined_pos_foot[0];
                xyz_goal_mm[2][i] = yz_inclined_pos_foot[1];
            }
        }
    }
private: 
    float yz_inclined_pos_foot[2];
};

class IK_leg {
public:
    
    void compute_leg_IK(){ 
        // in modern robotics: x_MR = x_me, y_MR= - z_me, z_MR = y_me, from MR to me frame: + 90� x rotation of the MR frame.
        if (incline_front_or_rear == 1){ 
            for (int leg = 2; leg < 4; leg ++) {
                double px = xyz_goal_mm[0][leg];
                double py = xyz_goal_mm[1][leg] - 0.05;
                double pz = xyz_goal_mm[2][leg];

                double r2 = px*px + pz*pz;
                double phi = atan2(pz, fabs(px));
                double safe = std::max(r2 - d1*d1, 0.0);
                double alpha = atan2(sqrt(safe), d1);
                legs_actuator_goal_rad[0][leg] = fabs(phi) - fabs(alpha);
                double D = (px*px + py*py + pz*pz - d1*d1 - a2*a2 - a3*a3) / (2 * a2 * a3);
                D = std::clamp(D, -1.0, 1.0);
                legs_actuator_goal_rad[2][leg] = atan2(sqrt(1 - D*D), D); 
                double s3 = sin(legs_actuator_goal_rad[2][leg]);
                double c3 = cos(legs_actuator_goal_rad[2][leg]); 
                legs_actuator_goal_rad[1][leg] = atan2(py, sqrt(r2 - d1*d1)) - atan2(a3 * s3, a2 + a3 * c3);
                
                if (leg == 1 || leg == 2) {
                legs_actuator_goal_rad[0][leg] = - legs_actuator_goal_rad[0][leg];
                legs_actuator_goal_rad[1][leg] = - legs_actuator_goal_rad[1][leg];
                legs_actuator_goal_rad[2][leg] = - legs_actuator_goal_rad[2][leg];
                }
            }

            for (int leg = 0; leg < 2; leg ++) {
                legs_actuator_goal_rad[0][leg] = 0;
                legs_actuator_goal_rad[1][leg] = 0;
                legs_actuator_goal_rad[2][leg] = 0;
            }
        }

        else {
            for (int leg = 0; leg < 2; leg ++) {
                double px = xyz_goal_mm[0][leg];
                double py = xyz_goal_mm[1][leg] - 0.05;
                double pz = xyz_goal_mm[2][leg];

                double r2 = px*px + pz*pz;
                double phi = atan2(pz, fabs(px));
                double safe = std::max(r2 - d1*d1, 0.0);
                double alpha = atan2(sqrt(safe), d1);
                legs_actuator_goal_rad[0][leg] = fabs(phi) - fabs(alpha);
                double D = (px*px + py*py + pz*pz - d1*d1 - a2*a2 - a3*a3) / (2 * a2 * a3);
                D = std::clamp(D, -1.0, 1.0);
                legs_actuator_goal_rad[2][leg] = atan2(sqrt(1 - D*D), D); 
                double s3 = sin(legs_actuator_goal_rad[2][leg]);
                double c3 = cos(legs_actuator_goal_rad[2][leg]); 
                legs_actuator_goal_rad[1][leg] = atan2(py, sqrt(r2 - d1*d1)) - atan2(a3 * s3, a2 + a3 * c3);
                
                if (leg == 1 || leg == 2) {
                legs_actuator_goal_rad[0][leg] = - legs_actuator_goal_rad[0][leg];
                legs_actuator_goal_rad[1][leg] = - legs_actuator_goal_rad[1][leg];
                legs_actuator_goal_rad[2][leg] = - legs_actuator_goal_rad[2][leg];
                }
            }
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

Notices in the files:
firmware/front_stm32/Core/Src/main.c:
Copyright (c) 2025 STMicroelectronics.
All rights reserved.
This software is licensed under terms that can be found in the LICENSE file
